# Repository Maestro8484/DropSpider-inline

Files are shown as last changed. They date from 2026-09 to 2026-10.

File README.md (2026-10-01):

# dropspider-inline

**DropSpider, Mechanism A: In-Line Single-Axle Clutch Spool (ISCS), Rev C.1.**
A Halloween prop, mounted on a porch ceiling or turned over on the porch beam's inside face (doc 06), that drops a foam spider 0.5 to 1.2 m when someone walks toward a doorway, then winds it back up and re-arms on its own. Zero power while waiting.

Code: https://github.com/Maestro8484/DropSpider-inline. Project page: https://theschmidtwithin.com/bench/#dropspider

Sibling project name reserved: `dropspider-tiltspool` (Mechanism B, servo-driven tilt-spool free-fall). Not started. This repo is Mechanism A only.

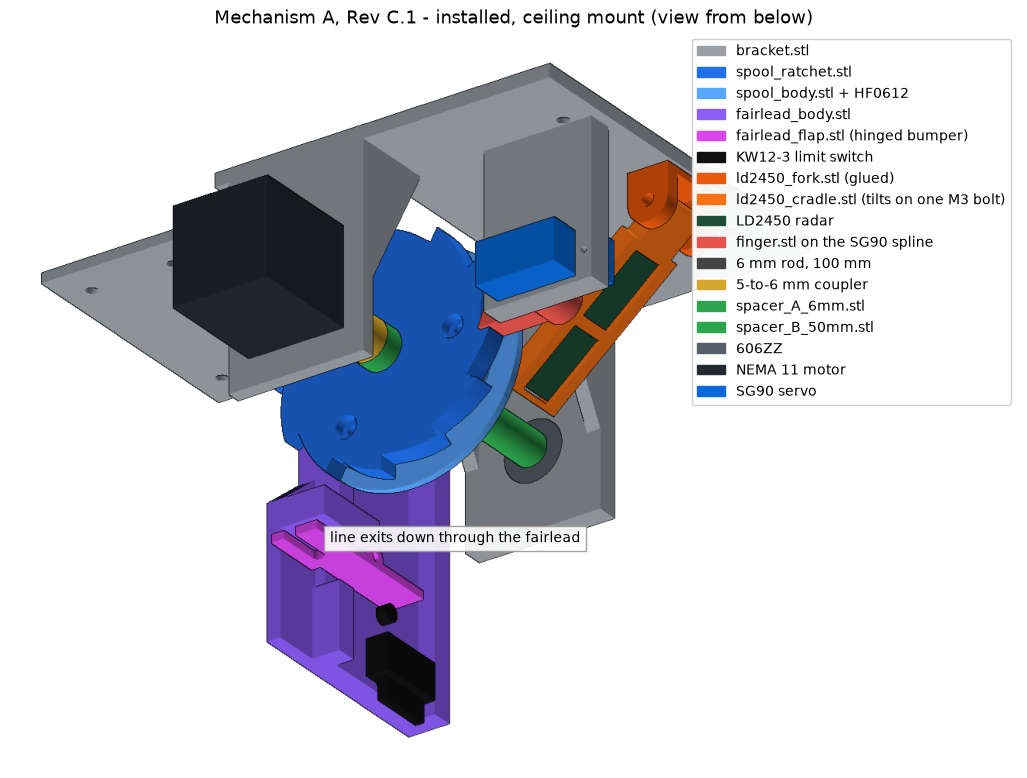
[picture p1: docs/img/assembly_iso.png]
Installed assembly


## How it works

Stepper motor to coupler to 6 mm rod. The spool rides the rod on a one-way clutch bearing. On a drop, the motor spins fast in the unwind direction and the spool runs down behind it; the clutch lets the spool lag but never overrun, so the motor sets the drop speed and the stopping height. On rewind the clutch locks and the motor winds the spider home, where the line's stop bead lifts a hinged flap under the fairlead and clicks a limit switch. A servo-driven finger in a ratchet then holds the spool with no power. An LD2450 radar at the door fires only on people walking toward it, timed so the spider arrives as they reach the doorway.

## Repo map

Each doc has one job, marked in bold below where it matters: a **handoff** holds only work still to do, finished work goes to the **changelog**, the order of future work is the **roadmap**, problems go to the **issues** list, bench results to the **log**, and everything else describes the device as it is now.

| Path | What |
|---|---|
| `docs/01_mechanical_design.md` | design spec, stack-up, lock mechanism, direction rules, print settings |
| `docs/02_electrical.md` | pin map, power, driver setup, logic-level check |
| `docs/03_sensor.md` | LD2450 (primary) and LD2410C (fallback): placement, trigger rule, app check |
| `docs/04_firmware.md` | cycle, serial commands, rewind math |
| `docs/05_assembly.md` | step-by-step assembly with pictures |
| `docs/06_installation.md` | doorway geometry, heights, fastening, safety |
| `docs/07_commissioning.md` | bench and on-site test checklist with pass criteria |
| `docs/08_open_items.md` | **issues:** what is verified, what is not, risks; closed items one line each |
| `docs/09_fairlead_switch.md` | fairlead, hinged flap and KW12-3 limit switch |
| `ROADMAP.md` | **roadmap:** every piece of work still to do, in order, one line each |
| `CHANGELOG.md` | **changelog:** finished work, newest first |
| `docs/handoff_task1_firmware.md` | **handoff:** bench tests T1 to T8, and the spool-to-flap fix before them |
| `docs/handoff_spool_onepiece.md` | **handoff:** one-piece spool and ratchet, no supports, bearing hole that grips, separator clear of the finger |
| `docs/handoff_sensor_bearings.md` | **handoff:** the LD2450 radar as the trigger (the name is historical; bearing care is in doc 01) |
| `docs/M1_fix_handoff.md` | **reference:** the Rev C.1 clutch fix and motor-led drop, why it works, and the T1 to T8 test table (the name is historical) |
| `cad/generate.py`, `cad/fairlead.py`, `cad/inverted.py` | source of truth for every printed part (`inverted.py`: the device turned over on the porch beam, doc 06) (`tools\regen_cad.ps1` rebuilds STLs and images) |
| `cad/stl/` | print-ready files. `cad/retired/` holds obsolete parts and their code, `docs/retired/` obsolete docs and pictures: do not print or follow them |
| `platformio.ini`, `src/`, `include/` | firmware, standard PlatformIO layout, 30-pin ESP32 DevKit V1 (38-pin NodeMCU-32S also works) |
| `secrets.ini.example` | template for `secrets.ini`: WiFi name, password, update password (never committed) |
| `docs/commissioning_log.md` | **log:** every bench and install result, dated, failures included |
| `bom/BOM.csv` | every part, ordered or still to buy |
| `scripts/update_firmware.bat` | double-click to update the firmware, by WiFi or by USB |
| `tools/esptool_noreset.py` | USB flashing helper the update script uses |
| `tools/console.py` | send console commands over USB or the network, print the replies |
| `tools/requirements.txt` | Python packages for the tools |
| `tools/*.ps1` | same as the .bat files for PowerShell; regenerate CAD and images |

## Quick start

1. Print the parts in `cad/stl/` (settings in doc 01).
2. Buy the "TO BUY" lines in `bom/BOM.csv`.
3. Assemble per doc 05.
4. Wire per doc 02. Meter the 5 V buck (must read 4.95 to 5.05 V) and set driver Vref to 0.85 V first.
5. Copy `secrets.ini.example` to `secrets.ini` and put in your WiFi name and password.
6. Plug the board in by USB, double-click `scripts\update_firmware.bat`, pick 2 (USB), then run doc 07 on the bench.
7. From then on, the web page at `http://dropspider.local` is the console, and firmware updates go over the network (doc 04).
8. Install per doc 06.

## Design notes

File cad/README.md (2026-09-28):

# cad/ - how the parts and pictures are made

Read this before changing any printed part or any picture in `docs/img`. It is the working memory for CAD in this repo.

## The short version

There is no CAD program. Every printed part is Python code. Run the code and it writes the STL files, checks them, and draws the pictures.

```powershell
pip install trimesh manifold3d shapely numpy matplotlib      # once
.\tools\regen_cad.ps1                                          # rebuild everything
```

`tools\regen_cad.ps1` runs three scripts in order:

| Step | Script | Writes | What it does |
|---|---|---|---|
| 1 | `cad/generate.py` | `cad/stl/*.stl` | Builds each part from boxes and cylinders, adds and cuts them (boolean operations, via manifold3d), turns each part to its print orientation, exports STL, then runs checks and prints a report |
| 2 | `cad/render.py` | `docs/img/` assembly, exploded, step1 to step6, lock_detail, base_layout, fairlead_rest, fairlead_home, fairlead_exploded, inverted_install | Places every part where it sits in the real device and draws shaded pictures with `raster.py` (a small built-in renderer, no graphics card needed). Takes 1 to 3 minutes |
| 3 | `docs/diagrams.py` | `docs/img/wiring.png`, `install.png` | Flat drawings made with matplotlib |

Same code, same output: the pictures and STLs are rebuilt identically every time.

## Files

| File | Holds |
|---|---|
| `generate.py` | Every part except the fairlead unit: bracket, spool body, ratchet disk, finger, spacers, shims. The `PARTS` table maps file names to functions. `assembly()` places every part in its installed position |
| `fairlead.py` | Fairlead body, hinged flap, KW12-3 switch model, hinge math. Run it on its own for the flap travel report |
| `sensor_mount.py` | LD2450 radar mount: the fork's ears and the cradle and `ld2450_fork_screw`, the bolted fork (2x M3, no glue), the only radar fork, cradle tilting on one M3 bolt. Run it on its own for its fit report: clear of every part at every tilt from 0 to 50 degrees |
| `inverted.py` | Inverted install (doc 06 alternative, approved 2026-09-27): the device turned over on two steel corner braces. `bracket_inverted()` (the 3 drilled holes), `fairlead_base()` (doc 09's unit as a block under the base, exported as `fairlead_base.stl`), the radar turned over under the servo end, brace stand-ins, a board box, `assembly_inverted()`, `porch()` and `view_inv()` (pictures with the floor down). Run it on its own for its report: watertight, face flat, clash (braces and board box included), radar view, line path, spool clearance, flap stops and roller push, screw heads, loads, heights |
| `retired/` | Obsolete parts and their code: `line_guide`, the glued `ld2450_fork`, the wall-install drafts (`wall_hinge.py` with hinge_plate, hinge_clip, tie_bar, strut; `wall_mount.py`, the braced shelf). Kept for reference, not run, not printed |
| `render.py` | All 3D pictures. One function per picture |
| `footprint_svg.py` | Laser-cutter SVG of the bracket's ceiling face with every hole, 1:1 mm, seen from below: writes `bracket_footprint.svg` in cad/, and `bracket_footprint_inverted.svg` with the three holes drilled for the inverted install |
| `raster.py` | The renderer (hidden surfaces, shading, outlines) |
| `stl/` | Print-ready output. Never edit these by hand |

## The coordinate frame (every doc uses it)

Units: millimeters.
- **y = 0** is the ceiling face of the bracket. **+y** points down toward the floor.
- **z = 0** is the outer face of the motor plate. **+z** runs along the rod toward the 606ZZ bearing plate.
- **Rod axis** at x = 0, y = 40. Servo tower on **+x**. Electronics pad on **-x**.
- **Line** leaves the spool at x = -25, z = 45 and runs straight down (+y) through the fairlead.
- Every clockwise or counterclockwise is seen from behind the motor (owner 2026-09-28): looking from -z along the rod toward the 606ZZ end. Spider falling = counterclockwise, winding up = clockwise, the HF0612 locks when the rod turns clockwise.
- Inverted install (`inverted.py`): the same frame, so y = 0 is the base's outer face and +y points UP in the porch. The line leaves the spool at x = 25, z = 45 and runs through the base (-y). Its pictures use `view_inv()` so the floor is down.

## Checks the scripts run (read the report every time)

| Check | Where | Pass |
|---|---|---|
| Every part is a closed solid (watertight, printable) | generate.py | `watertight=True` on every line |
| Nothing touches the spinning spool, 2 mm clearance | generate.py | `0.0 mm3 overlap` for bracket, fairlead_body, servo |
| No clashes between moving and fixed parts | generate.py | no `CLASH` lines |
| Finger tip reaches into the tooth root | generate.py | `engaged: True` |
| Finger seats in a tooth gap (rotates the ratchet through one tooth pitch in 0.25 degree steps) | generate.py | `True (window 6.75 to 11.75 deg)` for the Rev C.1 finger |
| Flap hard stop and switch travel | `python fairlead.py` | hard stop about 14.75 deg; roller push at least 3.4 mm |
| Line path open through the fairlead bore and the flap slot | `python fairlead.py` | `line path clear ... True` twice (a flipped bore once printed solid) |

## Changing a part: the routine

1. Edit the part's function in `generate.py` or `fairlead.py`. Keep dimensions as named constants at the top where they already are.
2. Run the checks (`python fairlead.py`, `python inverted.py`, `python sensor_mount.py`, as the part needs; they only print) and read the report. Any `CLASH`, `watertight=False`, or lost clearance means stop. Export only the changed part's STL (`G.PARTS["name"]()`), not every STL (owner 2026-09-27: update only the parts that need it).
3. Re-render a picture only if the owner asks for it.
4. Update the doc that describes the part (01 for the spool, finger and bracket, 09 for the fairlead).
5. Tell the owner which STL changed and whether an already-printed part is now out of date.
6. Geometry changes need the owner's approval (CLAUDE.md hard constraints).

## Lessons already learned (do not repeat these)

- **Print orientation lives in code.** Parts that must print a certain way have a `*_print()` function that turns them before export. Never ask the owner to rotate in the slicer.
- **Recesses face up.** A recess on the bed side leaves a ceiling with nothing under it; Bambu Studio reports "floating regions" or "isolated object". The finger v1 failed this way.
- **No overhangs on the spool.** The spool is two parts (body and ratchet disk) so both print flat with zero supports and no scars in the line channel. The spool hub must end flush with its flange; a stub under the flange forced supports once.
- **Thin features fail in PLA.** Keep printed walls at 1.2 mm or more near loads. Finger v1 had 0.9 mm walls and a half-width tip; the current finger is 7 mm wide with a 7 mm plate.
- **Tip shapes must match the teeth.** An unbeveled 7 mm finger could not seat in any tooth gap. The 20 degree bevel on the ramp side fixed it. Re-run the seating check after any finger or tooth change.
- **Nothing may stick out of the ceiling face** (y = 0). That is why the fairlead's two M3 screws are countersunk flush (owner: no glue).
- **Directions are easy to get backwards.** One-way clutch: it only lets the spool overrun in the direction the rod can drive it (flaw M1). Check any direction claim against the frame above before writing it into a doc.
- **The bracket is printed and final.** Changes should bolt or screw to it, not require reprinting it. No glue (owner 2026-09-26).

- **Printed holes come out small on the owner's printer.** A 4.8 mm socket printed 4.5; a 10.0 spacer in a 10.2 hole was too tight. Draw slide fits 0.2 to 0.3 mm a side bigger, and free-turning pins about 0.25 mm a side. A fit check (2026-09-26) found 9 fits wrong; see the git log. **Bearing press fits: the HF0612 would not go into a 10.0 hole, 10.2 was tight, and a 10.7 hole printed at 10.7 and was loose (owner 2026-09-28).** Its hole is now drawn 10.3 (firm press); the disk's stub hole is the same 10.3. The 606ZZ seat drawn 16.8 would not take the bearing even heated (2026-09-27); it is drawn 17.0, not yet fitted.
- **A boolean cut can silently miss.** The fairlead bore once sat at y -78 because of a sign flip, so the part printed solid. Every functional void now has a check that fails if it misses (line path check, flatness check in `fairlead.py`).
- **A face something mounts on must be one plane.** Check the distinct levels of the faces under it (the switch face and the fairlead's mounting face each had a 0.8 to 1 mm step the owner had to shim).
- **A recess on the bed side needs stepped bridging**, or it prints a roof over air. The finger's screw-head recess uses it: two strips, then a square, then the round hole.
- **Every member starts on the bed plane**, and ribs run the full height to both ends.
- **`lbl()` in render.py takes render-world coordinates, (x, z, -y), not assembly coordinates.** A label given (x, y, z) lands somewhere else on the page (wall_install.png, 2026-09-27).
- **An L-bracket with two end braces cannot print on its side** (the prior-art advice for a strong corner): the second brace would hang over air. It prints shelf-down with the plate and braces standing; the braces keep the corner's layer bonds under 1 MPa, so the weaker orientation costs nothing that matters.

## Adding a new picture

Write a function in `render.py` that builds a list of `(mesh, color)` pairs from `G.assembly()` (or from parts moved apart for an exploded view), calls `raster.render(items, elev=..., azim=..., W=..., H=...)`, and saves with `save()`. Add the function to the `__main__` line at the bottom so `regen_cad.ps1` builds it. Use `rview()` so the ceiling is at the top of the picture.

## Known limits

- Python 3.10 or later. `trimesh` path functions that need `rtree` (area of a cross-section) are avoided; install `rtree` if you add one.
- Rendering is CPU only; big pictures take a minute or two.
- The owner's chat session can edit these text files but cannot write STL or PNG files into the repo. After an owner CAD change, run `regen_cad.ps1` here.

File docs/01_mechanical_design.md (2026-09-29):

# 01 - Mechanical design: Mechanism A, In-Line Single-Axle Clutch Spool (ISCS), Rev C.1

Status: **released for build, Rev C.1** (clutch flipped, motor-led drop; see `M1_fix_handoff.md`). Owner: lead mechanical engineer. Source of truth for geometry: `cad/generate.py`.

Installed assembly

## What it does, in one paragraph

A foam spider hangs on 6 lb nylon monofilament fishing line wound on a spool. The spool sits on a one-way clutch bearing (HF0612) on a steel rod driven by a small stepper motor. A servo-held finger locks the spool at the top with zero power. On trigger, the motor winds a hair to lift the tooth off the finger, the finger swings out, and the motor spins fast in the unwind direction. The spool runs down behind it on the clutch: it can fall as fast as gravity allows but never faster than the motor, so the motor sets the top speed and the stopping point. After a short hang, the motor winds the spool back up (the clutch locks in that direction), the finger swings back into the ratchet teeth, the motor eases the spool down onto a tooth, and everything powers down.

## Why this layout (decisions already made, do not re-open without cause)

| Decision | Reason |
|---|---|
| Spool on a one-way clutch, motor-led drop (Rev C.1) | A one-way clutch only lets the spool overrun in the direction the motor drives, so the spool cannot free-fall past a stopped motor (flaw M1 in Rev C). Instead the motor runs ahead in the unwind direction; the spool lags behind it at gravity and can never overrun it. The unpowered motor's drag (measured too high) never matters because the motor is always driven. |
| Everything on one rod ("in-line") | Strength and simplicity: no gears, belts, or offset shafts. One part to align. |
| Ratchet + servo finger for the hold | Zero power while armed, no hum, no heat. The load pushes the finger onto a printed ledge, not into the servo. |
| Stepper, not a DC gearmotor | Fixed step count per move; the fairlead's limit switch marks home. |
| Hard stop at the top = bead lifts a hinged flap under the fairlead, which presses a KW12-3 switch; the flap then bottoms on the fairlead (Rev C.1, doc 09) | Rewind length varies by up to half a turn after each drop (see "End of drop"), so a counted stop alone is not reliable. |
| Spool split into two parts | Both print flat with zero supports; no support scars in the line channel. |

## Parts on the rod, motor to bearing (z = distance from the motor plate's outer face)

| z (mm) | Part | Notes |
|---|---|---|
| -32 to 0 | NEMA 11 motor | Mounted on the outside of the motor plate, 4x M2.5 |
| 10 to 30 | 5-to-6 mm rigid coupler | Motor shaft fills the 5 mm side. Blue Loctite on both set screws. |
| 20 to 120 | 6 mm hardened rod, 100 mm | Clamped in the coupler only; everything else slides on it |
| 30 to 36 | spacer_A_6mm | 12 mm across, so it stops on the ratchet disk's face instead of dropping into its 10.3 mm center hole. Sets the disk in the finger plane. Adjust with shims (see below). |
| 36 to 43 | spool_ratchet | 12 teeth, full 7 mm (tip r 33, root r 29); a plain plate, flat both faces. The finger engages z 36 to 42, so the shield on the z 43 face clears the finger by 1 mm |
| 43 to 44.5 | spool_shield | Flat 1.5 mm disc, 64 mm across like the spool flange: keeps the line off the teeth. Clears the finger's top (z 42) by 1 mm |
| 44.5 to 50 | spool_body with HF0612 pressed in | Flat face on the shield; line channel z 44.5 to 48. The HF0612 (z 38 to 50) runs through all three parts and centres them; 3x M3x8 from the motor side, heads 5 deep in the disk |
| 50 to 100 | spacer_B_50mm | 9.6 mm across; the last 1 mm at the 606ZZ end is 8 mm across so it presses only on the bearing's inner ring, not its shield |
| 100 to 106 | 606ZZ in the bearing plate | Supports the rod end |

**The one measurement that matters:** the ratchet disk must straddle the finger. Finger plate is z 35 to 42 (7 mm thick); disk is z 36 to 42. After the motor and coupler are on, measure from the motor plate's outer face to the coupler's free end. If it is not 30 mm, change spacer A by the difference using `shim_1mm` / `shim_2mm` (or reprint spacer A). The spool floats between spacer A and spacer B, so the stack must be snug, not tight.

## The lock (read this before touching the servo angles)

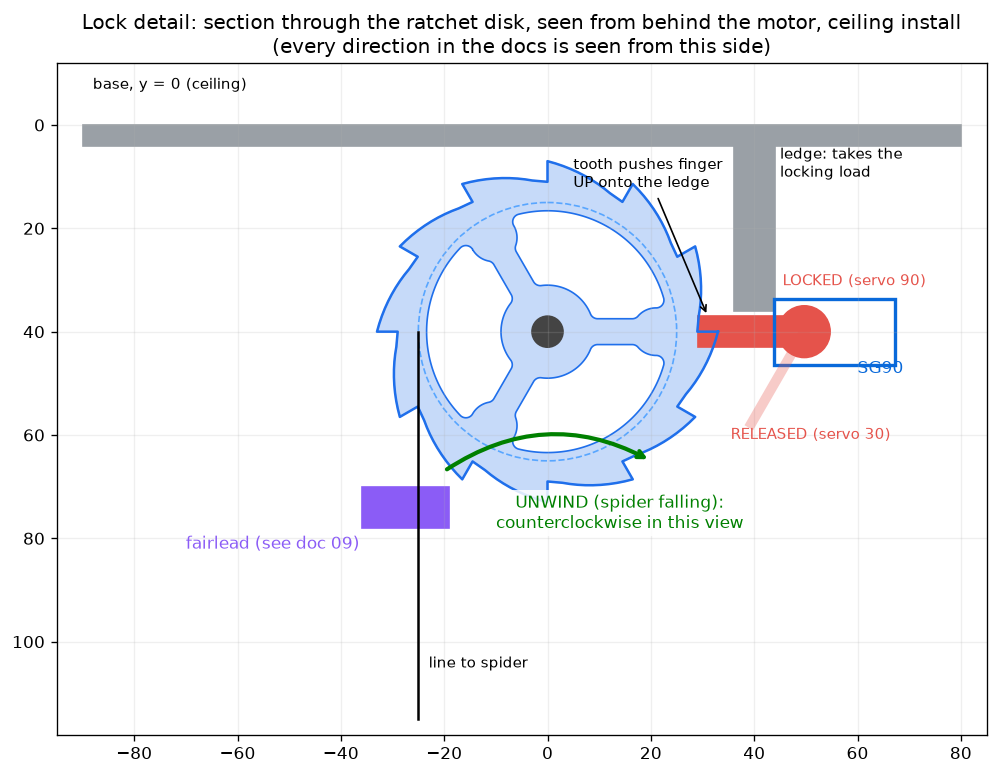
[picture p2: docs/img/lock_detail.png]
Lock detail


- **Every direction in these docs is seen from behind the motor**: standing behind the stepper motor, looking along the rod toward the spool (the picture is drawn that way). The spool turns **counterclockwise** when the spider falls and **clockwise** when it winds up.
- The steep faces of the teeth block that direction. The tooth pushes the finger toward the ceiling, onto the **ledge** printed on the bracket. The ledge takes the load; the servo carries almost none.
- Finger locked = level, pointing at the rod (default servo 90). Released = swung toward the floor by 60 degrees (default servo 30). Both are set at commissioning.
- Lock sequence (firmware does this): motor holds the spool, finger goes in, motor eases the spool down (counterclockwise) up to 1/12 turn until a tooth lands on the finger, the clutch then slips so the motor runs on alone, motor off, servo lets go.
- Release sequence (M2): with the spider hanging, the tooth pins the finger. The motor winds the spool clockwise about 1/12 turn while the finger swings out, so the finger rides up the tooth's ramp. Never release with the motor off.
- The finger (Rev C.1) is 7 mm wide and 7 mm thick, level with the ledge it rests on (z 35 to 42); the ratchet disk is z 36 to 42, so a spline 1 mm higher or lower than expected still leaves 5 mm of finger on the disk. Its tip face is beveled 20 degrees so the corner on the ramp side sits 2.5 mm back; the steep-face side reaches full depth. Checked in CAD: it seats in a tooth gap over a 5 degree window. No horn: a hub under the finger reaches down onto the SG90 spline (4.8 mm across the teeth, 3.4 mm tall, tip about 2 mm short of the ledge, all measured by the owner). The socket is drawn 5.0 mm so it prints about 4.7 (a 4.8 drawing printed 4.5 on the owner's printer), a light press on the spline. The spline tip bottoms on a 1.5 mm floor, which sets the height; the horn screw goes in from the top through a 7.4 mm recess (prints about 7.1). Print it flat top face down (as exported); the hub stands up.

## Direction rules (the only things that can be assembled backwards)

1. **Line exits on the electronics-pad side** of the spool and goes straight down through the fairlead. Wind it so pulling the line spins the spool counterclockwise, seen from behind the motor. **Inverted install (doc 06):** the line exits on the **servo side** (x 25) and goes through the 5 mm hole in the base; the winding sense, the clutch, the finger and the firmware `dir` are all unchanged, because the spool still turns counterclockwise (seen from behind the motor) when the spider falls. The finger's own weight now rests it toward the ledge.
2. **HF0612 orientation (Rev C.1, flipped from Rev C):** with the spool on the rod and the rod held still, the spool must **lock counterclockwise** (seen from behind the motor) and spin freely clockwise. Put the other way: the rod turning clockwise drives the spool. If backwards, press the bearing out and flip it.
3. **Motor rewind direction:** set in firmware (`dir 0/1`), no rewiring.

## Line and hard stop

From the spool outward: **6 lb nylon monofilament** (clear fishing line, tied straight to the barrel with an arbor knot; no elastic, no braid, owner's call 2026-09-26), through the fairlead (3.2 mm throat) and the flap's slot, then the **8 mm hard plastic bead** (lifts the flap at home; too big to pass the slot), then a small barrel swivel (stops the spider spinning the line into twists), then the spider.

Why monofilament: it winds cleanly, it is nearly invisible, it is gentler on the PLA fairlead than braid, and it stretches (roughly 15 to 25 percent before it breaks, a typical figure for nylon mono, not measured here). That stretch is the shock absorber. At 6 lb (about 27 N) it is also a fuse: it snaps before it can pull the device off the ceiling.

## End of drop and why the line must stretch

Rev C.1 note: the motor now stops the spider short of the knot on every normal drop, so this slam only happens if the motor loses its grip mid-drop. The line's own stretch is the backstop.

The spool is free, so nothing stops the spider until the line runs out. At that moment the knot swings to the bottom of the barrel and the pull goes straight into the rod. Without give in the line (braid), a 100 g spider falling 0.7 m produces a shock of order 100 N or more, enough to snap the knot, the PLA, or the ceiling anchors. About 750 mm of 6 lb mono stretches roughly 70 mm and holds the peak near 12 N for a 60 g spider (estimate from the typical stretch above), under half its breaking strength, and the spider bounces. **Never swap in braid or fluorocarbon (both stretch little) without putting a 150 mm elastic snubber back at the barrel.**

The same swing means the knot can end up to half a turn either side of the bottom, which is why the rewind overshoots by 0.75 turn and relies on the bead stop.

## Materials and print settings

| File | Qty | Orientation | Infill | Walls | Supports | Brim |
|---|---|---|---|---|---|---|
| spool_body.stl | 1 | as exported, flange down | gyroid 40% | 4 | none | none |
| spool_ratchet.stl | 1 | as exported: flat shield face down, counterbores up | gyroid 40% | 4 | none | none |
| spool_shield.stl | 1 | as exported, flat | gyroid 40% | 4 | none | none |
| bracket.stl | 1 | base down | gyroid 40% | 4 | tree, **not** build-plate-only | none |
| fairlead_body.stl | 1 | as exported (flat side down) | gyroid 40% | 4 | none | 5 mm (big flat footprint, stops corner lift) |
| fairlead_flap.stl | 1 (+1 spare) | as exported (flat side down) | rectilinear 100% | 4 | none | 5 mm, 0.1 gap |
| ld2450_cradle.stl | 1 | as exported (flat, face plate down, 6.7 mm tall) | gyroid 40% | 4 | none | none |
| finger.stl | 1 (+1 spare) | as exported (flat top face down, hub standing up) | rectilinear 100% | 4 | none | 5 mm, 0.1 gap |
| spacer_A_6mm.stl, spacer_B_50mm.stl | 1 each | on end | rectilinear 100% | 4 | none | 5 mm, 0.1 gap |
| shim_1mm.stl, shim_2mm.stl | only if needed (05 step 8) | flat | rectilinear 100% | 4 | none | none |
| fairlead_base.stl | 1, inverted install only (doc 06), instead of fairlead_body | as exported (17 mm tall) | gyroid 40% | 4 | none | 5 mm |
| ld2450_fork_screw.stl | 1, both installs: the only radar fork, bolted with 2x M3, no glue (the glued ld2450_fork is retired) | as exported (plate face down, ears standing up) | gyroid 40% | 4 | none | none |

PLA for everything. Print the finger in PETG if any is loaded. 5 top and bottom layers. `cad/retired/line_guide.stl` is obsolete; do not print it.

## Press fits and fasteners

- HF0612 into spool body: the hole is drawn 10.3 mm for the 10.0 mm bearing, a firm press (owner 2026-09-28: 10.0 would not take the bearing at all, 10.2 was tight, and 10.7 printed at 10.7 and was loose). The disk's center hole over the stub is the same 10.3 mm. Press in with a vise or clamp. Too tight: warm the hub with a hair dryer. Too loose: one drop of CA on the outside. Never glue near the rollers.
- 606ZZ into bracket: drawn 17.0 mm for the 17.0 mm bearing; it prints 0.1 to 0.2 small, which is the press. Same method. (Was 16.8: would not go in even heated, owner 2026-09-27.)
- Spool disk to body: 3x M3x8 self-tapping into 2.5 mm holes.
- Fairlead body to pad: 2x **M3 countersunk (flat-head) screws, 8 to 10 mm**, put in from the ceiling side down through the x = -32 pad holes, heads flush with the ceiling face, cutting their own thread into the fairlead's rail (2.5 mm pilots). No glue (owner 2026-09-26). The pad holes need a 90 degree countersink so the heads sit flush: new bracket prints have it; on an already printed bracket, twist an 8 mm drill bit by hand in each of the two holes from the ceiling side until a screw head sits flush or just below. Nothing may stand proud of the ceiling face, which is why the heads are countersunk. At home the motor's pull lands on the fairlead's flap stop, about 2 N.
- KW12-3: 2x M2 x 12 + nuts through the slotted holes. Hinge pin: an M2 bolt, 16 to 20 mm, threaded into the body, free in the flap (filament was too tight, owner 2026-09-26).
- Motor: 4x M2.5x6.
- Inverted install (doc 06 alternative): 2x M3 x 12 (fairlead_base, from inside the base, cutting their own thread), 2x M3 x 10 + nuts (radar fork, nuts inside). Brace screws and bolts are the owner's. The wall install draft's fasteners are superseded.
- SG90: its own two tab screws.

## Bearing care

- **HF0612:** never clean with carb cleaner or solvent spray; it strips the grease and attacks the plastic roller cage. If gritty: isopropyl alcohol flush, dry, one drop of light machine oil. Never grease it.
- **606ZZ:** shielded and greased for life; leave it alone.
- Sluggish drop: check spool end play (0.3 to 0.5 mm), then the fairlead bore, then the HF0612 by hand. See `handoff_sensor_bearings.md`.

## Limits of this revision

- Ceiling mount only. Wall mount changes where the line exits and the fairlead does not fit.
- Spider: soft foam, **60 g or less** (Rev C.1: the motor must stop it at the end of the drop), nothing hard or pointed.
- Drop length set by line length, about 0.5 to 1.2 m.

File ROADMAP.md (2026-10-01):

# Roadmap

Every piece of work still to do, in order. One line each; the handoff holds the detail. Finished work goes to `CHANGELOG.md`, problems and unknowns to `docs/08_open_items.md`, bench results to `docs/commissioning_log.md`. Rules for these files: the `repo-docs` standard in the owner's global Claude setup.

| # | Work | Whose | Status | Detail |
|---|---|---|---|---|
| 1 | Firmware: line between the spool and the flap is about 72 mm in the inverted install (fairlead v2) (firmware assumes 40); factory drop distance must fit the shorter line | team | next | `docs/handoff_task1_firmware.md` step 1 |
| 2 | Bench tests T1 to T8 of the Rev C.1 motor-led drop, with the mechanism assembled | team with the owner | next, needs the mechanism built | `docs/handoff_task1_firmware.md` |
| 3 | One-piece spool and ratchet: no supports, bearing hole that grips (the HF0612 slips a bit), separator inside the finger's reach (the finger caught the shield and was cut back) | team with the owner | later: the owner keeps the current stack (2026-10-01) | `docs/handoff_spool_onepiece.md` |
| 3b | Build the inverted install: print `fairlead_base` and `fairlead_flap_inv` (fairlead v2), `ld2450_fork_screw`; drill the five base holes; braces and their holes | owner | any time; bench first | build guide sections 06 and 11, doc 06, open item V18 |
| 4 | LD2450 radar as the trigger, including the spider-in-view problem; tests S1 to S5 | team | waiting on T1 to T8 | `docs/handoff_sensor_bearings.md` |
| 5 | Hang it on the porch, walk tests, arm | owner with the team | waiting on 2, 3 and 4 | `docs/07_commissioning.md`, build guide section 12 |
| 6 | Calibrate card on the web page: walks the bench steps with Pass and Fail buttons (replaces the planned `test` console command) | team | later | build guide section 09, "Planned" |
| 7 | Enclosure for the controller board | owner | later | `docs/08_open_items.md`, Rev D candidates |
| 8 | Static IP address (DHCP only today) | team | later, only if the router moves it | `docs/08_open_items.md`, known limits |

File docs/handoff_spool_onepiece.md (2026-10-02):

# Handoff: one-piece spool and ratchet (Rev C.3)

**Later, not now:** the owner keeps the current three-part stack and its cut-to-length shims (2026-10-01); this is the plan for the next spool. Redesign the three-part spool stack (`spool_ratchet`, `spool_shield`, `spool_body`) as one part that prints with no supports, grips the HF0612 one-way bearing so it cannot turn in its hole, and keeps the line separator out of the finger's reach. For a CAD session working with the owner (Joe).

## Ground truth first

This file is a work order, not a record. The repo on disk wins: `cad/generate.py` is the source of truth for every dimension below. If this file and the code disagree, the code is right and this file is stale; say so out loud. Staleness check:

```
git log -1 --oneline                                   # where the repo is now
git log -1 --oneline -- docs/handoff_spool_onepiece.md # when this file was last true
```

## Before you start

1. **The bearing turns in the plastic** (owner confirmed 2026-10-01), only under more load than the spider's weight; the clutch on the rod is fine. Step 3 fixes it.
2. **What is left of the finger.** Joe cut about 5 mm off the finger's face with flush cutters so it stopped catching the separator disc. Ask whether he cut its thickness (along the rod) or its length (toward the teeth), and how much finger now sits on the ratchet teeth (look edge-on at the lock angle). Either cut means less tooth engagement than the design's 7 mm; the new spool must let a fresh, uncut `finger.stl` work.
3. **Bearing hole 0.1 mm smaller.** Joe confirmed 2026-10-01: 10.3 to 10.2 (10.2 printed tight before; 10.3 now slips a bit under more load than the spider's weight).
4. Run `cd cad; python generate.py` and confirm every check passes before changing anything, so a later failure is yours.

## Read first

1. `CLAUDE.md`, especially the direction rule (every clockwise is seen from behind the motor) and "edit `cad/generate.py`, never the STLs".
2. `cad/README.md`: frame, rebuild routine, checks, lessons (the HF0612 press-fit history is there: 10.0 would not take it, 10.2 tight, 10.7 loose, 10.3 chosen).
3. `cad/generate.py`: `spool_ratchet`, `spool_shield`, `spool_body`, `ratchet_poly`, `spoke_windows`, `hole_chamfer`, `finger`, the finger seating check, and `assembly()`.
4. `docs/01_mechanical_design.md`, the stack table (z 30 to 106) and the print table.
5. `docs/05_assembly.md` steps 1 to 9 and the build guide's spool steps, which this part changes.

## The work, in order

1. **One part, three zones along the rod.** Ratchet (12 teeth, tip r 33, root r 29, ramps rise clockwise and steep faces block counterclockwise, seen from behind the motor; keep `ratchet_poly`), then a separator, then the barrel and the far flange. No screws, no counterbores. The HF0612 presses in from the flange side as now.
2. **Separator smaller than the finger's reach.** Today's shield is r 32, out past the finger's tip (closest approach r 29.38), so when Joe shimmed the stack along the rod the finger rode onto it. Make the separator r 28 or less (at least 1 mm inside the finger tip), so the finger can overlap it along the rod and never touch it. It only has to keep the line off the teeth: about 720 mm of 6 lb mono is under 5 turns on the r 25 barrel, one layer. Check that claim against the line length in doc 06 and say the margin in the report.
3. **Bearing hole that grips.** Standard printed press-fit: crush ribs (small ribs that the bearing shaves flat as it goes in) rather than a plain round hole. Owner's number is a plain 10.2 hole; offer crush ribs (10.4 hole, 6 to 8 ribs reaching in to 10.1) as the alternative if 10.2 needs sanding to go in, plus the existing 0.4 lead-in chamfer at the flange side. Name the source you borrow the rib sizes from (guard 2: prior art first).
4. **Prints with no supports, lying on one face.** Recommended: ratchet face on the bed (the teeth are plain vertical walls; the separator and barrel are smaller, so they stand on it with no overhang). The far flange then overhangs the barrel: give its underside a 45 degree chamfer, or keep it no wider than a 45 degree slope allows. The barrel is only about 3.5 mm wide today; there is room to widen it along the rod (Joe's build needed about 4 mm of shim on the motor side and 5 mm on the 606ZZ side, and spacer B is 50 mm), so take width from the shims rather than steepening the chamfer. Every hole edge on the bed gets the 0.4 chamfer.
5. **Line anchor built in.** Today the owner drills it by hand (`docs/05_assembly.md` step 5); the new part should have it printed in. What it must do: hold the 6 lb mono so it can never slip round the barrel, even when the spider runs all the line out (about 27 N, the line's breaking pull), with no glue doing the holding and nothing touching the rod.
   - **Where:** one hole through the barrel skin, in the middle of the barrel's width (between the separator and the far flange), at a spot where a spoke window lies behind the skin, midway between two spokes so a spoke never blocks it.
   - **How the line goes:** in through the hole from outside, out through the window's open end at the far flange face, tied round a 10 mm stub of 1.75 mm filament (a double overhand knot), pulled back so the stub lies across the hole inside the window. A drop of CA on the knot only. The stub cannot pull through.
   - **Hole shape:** about 1.2 mm drawn (printed holes under about 1 mm close up; check it takes a 1 mm drill). With the part printed ratchet down, the hole runs sideways, so draw it as a teardrop with the point up so its roof prints without sagging. Angle it so the line leaves the barrel along the winding direction (clockwise, seen from behind the motor), so the first turn wraps over the line's tail and the line never kinks at the hole's edge. Round the outer edge of the hole (0.4) so it cannot nick the line.
   - **Window side:** leave the window big enough for fingers or tweezers to fish the line out and seat the stub, and check the stub (10 x 1.75 mm) lies inside the window clear of the hub and the HF0612 at every angle.
   - **Alternative to offer, not the default:** a printed post or bar across the window to tie round instead of the filament stub. It saves the stub but is harder to tie in a small window; the stub is what the owner uses now.
   - **Ruled out:** an M3 set screw in the spool as the anchor (owner asked 2026-10-01). A screw into the rod locks the spool to the rod and defeats the one-way bearing; a screw onto the HF0612's thin drawn-steel shell bends it and jams the rollers.
6. **Keep the light-weight windows** (`spoke_windows`) if they still print with no bridging in this orientation; they run straight through along the rod, so they should.
7. **Fit the stack along the rod.** Total length, spacer A and spacer B (or new shims) must put the ratchet teeth across the finger's full 7 mm with the separator clear. Write the new z table.
8. Export only the new part's STL, `spool_onepiece.stl`. Move `spool_ratchet`, `spool_shield` and `spool_body` to `cad/retired/` with a one-line "Retired, superseded by spool_onepiece" note, once Joe has the new one in hand.

## Tests

Run in the model, results in the session report and the changelog line:

- `python generate.py`: finger seating check passes (seats in a tooth gap), no clashes, swept clearance clear, with a fresh uncut finger.
- Finger to separator: no contact with the stack slid 5 mm either way along the rod (Joe's shim range).
- Overhang report for the print orientation: nothing off the bed steeper than 45 degrees except the windows' straight walls.
- `python inverted.py`: line path and every inverted check unchanged.

On the bench, logged by Joe in `docs/commissioning_log.md`: the HF0612 presses in by vise and does not turn in the hole under a hand twist against the lock; spool free clockwise and locked counterclockwise with the rod held (seen from behind the motor); finger drops into the teeth at the lock angle with no catching.

## Done when

`spool_onepiece.stl` is printed, the bearing holds, the finger engages a fresh uncut finger with no catching, and the docs say so.

## Rules for the session

- Make the part and stop. Slicer settings are Joe's; answer slicer questions only when he asks.
- Export only the changed STL; no full rebuild, no mass picture regeneration unless Joe asks. Update only the build guide steps and pictures this part touches.
- Every direction is seen from behind the motor.
- Decisions go to Joe as one flat numbered list, the question in bold on each item.
- Plain English, no em dashes, no arrows.

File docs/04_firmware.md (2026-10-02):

# 04 - Firmware

What the code does, how to load it, and every command it takes.

## Where it lives

Standard PlatformIO layout at the repo root. Board in use: 30-pin ESP32 DevKit V1 (PlatformIO board `nodemcu-32s`, same chip as the 38-pin NodeMCU-32S), Arduino framework, platform pinned to `espressif32@6.7.0` (Arduino core 2.0.16).

| File | What |
|---|---|
| `platformio.ini` | board, pinned versions, USB port, network update target |
| `secrets.ini` | network name, network password, update password. Not in git. Copy `secrets.ini.example` |
| `include/config.h` | every pin and fixed number, and the factory defaults |
| `src/main.cpp` | start-up order only |
| `src/machine.cpp` | the cycle, stepper, finger servo, radar pin, BOOT button, limit switch |
| `src/console.cpp` | the text commands, shared by the USB console and the web page |
| `src/web.cpp` | WiFi, the web page, network firmware updates |
| `src/settings.cpp` | tunables saved in flash |

Libraries, both pinned in `platformio.ini`, both downloaded by PlatformIO on the first build:

| Library | Why this one |
|---|---|
| ESP32Servo 3.0.6 | servo pulses from the ESP32's own PWM hardware |
| FastAccelStepper 0.33.14 | step pulses from the ESP32's pulse hardware with speed ramps, so a rewind does not freeze the console or the web page. The Rev C handoff timed each pulse by hand and froze everything for 2 to 3 s |

WiFi, web server, mDNS (the `dropspider.local` name), ArduinoOTA (network upload) and Update (upload page) are all built into the ESP32 core. No other libraries.

## Load the firmware

First time on a new PC: install VS Code and its PlatformIO extension, copy `secrets.ini.example` to `secrets.ini` and fill it in, then open this folder in VS Code.

| Way | How |
|---|---|
| Network | board must be on the network already. Double-click `scripts\update_firmware.bat` and pick 1, or VS Code env `ota` and Upload. No buttons. It retries up to 3 times, because the first try sometimes drops |
| USB | double-click `scripts\update_firmware.bat` and pick 2. It builds and loads it; the 30-pin board goes into flash mode by itself. If a board does not (the first 38-pin board did not), the script asks you to hold BOOT (marked IO0 on some boards), tap EN, let go of BOOT, and writes through `tools/esptool_noreset.py`. Port is COM13 in the script and `platformio.ini` |
| Web page | open `http://dropspider.local/update`, log in as `admin` with the update password, pick `.pio/build/nodemcu-32s/firmware.bin` |

The 30-pin DevKit V1 in use enters flash mode on its own, so VS Code's plain Upload works too. The first 38-pin board did not.

Every network update switches the motor and servo off first. After any update the board restarts and, as always, does not rewind on its own.

## Network

- Joins the home network in `secrets.ini` by DHCP (the router hands out the address). Static address: not yet.
- A different network saved from the web page's Network card wins over `secrets.ini`. Save it empty to go back.
- If it cannot join in 15 s it makes its own network `DropSpider-setup` (password `dropspider`), page at `192.168.4.1`.
- Page at `http://dropspider.local` or at the address printed on the USB console at start-up (`wifi` command prints it again).

## The web page

The web page is the console on your phone or PC. Every button sends a console command, and the page's Console card shows everything the board prints, so the page and the USB console always agree.

| Card | What is on it |
|---|---|
| Status | state, chips (armed, spider home, radar, motor powered, fault), drop count, last trigger, last rewind, last drop as measured by the rewind |
| Run | Drop it now, Arm or Disarm, Stop, Motor and servo off, Clear fault |
| Bench: finger servo | live angle, nudge 1 or 5 degrees, go to lock or release angle, store the current angle as lock or release |
| Bench: motor | jog one turn or 1/8 turn each way, Rewind, Lock, Release |
| Settings | every tunable, applied as you change it; Save settings keeps them after power loss |
| Console | the live log and a command box |
| Network | save a different home network and restart |
| Firmware | link to the update page |

## Cycle (Rev C.1, motor-led drop)

```
READY (armed) --radar or BOOT button-->
  RELEASE: driver on; finger swings out while the motor winds the spool up 1/12 turn (M2),
           wait relms (250 ms)
  DROP:    motor unwinds dropmm at up to droprpm, starting at dropacc and stopping at dropdec;
           the spool falls behind it on the clutch and can never pass it. Motor holds at the bottom
  --settle 1.5 s--> REWIND (stops the moment the limit switch closes; without the switch,
                    the drop + 0.75 turn overshoot and the bead stops on the eyelet)
  --> LOCK (finger in; seat move lets the spool down 1.2/12 turn at 30 rpm onto a tooth,
            the clutch slips once it lands; driver off; servo off 0.7 s later)
  --> LOCKOUT 20 s --> WAIT FOR THE DOORWAY TO CLEAR (radar LOW for 2 s) --> READY
```

- The driver is on from the release to the end of the lock. Never drop with the driver off: the unpowered motor drags too much for a clean fall.
- Armed and ready: driver off, servo off. Only the ESP32 and the radar draw power.
- Boot: driver off first thing, finger to lock, never rewinds on its own. See "Home at boot" below.
- The machine runs on its own task, so console, page and network updates stay live during a cycle. `stop` works mid-drop and mid-rewind.

## The drop's two rates

FastAccelStepper 0.33.14 has one acceleration value per move, not separate start and stop rates. It does recompute the stop when the acceleration is changed mid-move (`setAcceleration` then `applySpeedAcceleration`). So the drop starts at `dropacc`, and the machine task, every 2 ms, works out how far the stop at `dropdec` needs from the current speed. When the move gets that close, plus a margin of 10 ms of travel and 50 steps, it switches to `dropdec`. The margin matters: switched too late, the library overshoots the end and reverses back to it.

If `dropdec` is set equal to or above `dropacc`, no switch happens and the whole drop uses `dropacc`.

Unit check: one microstep = pi x 50 mm / 1600 = 0.098 mm of line. 1 m/s is about 610 rpm. 100000 steps/s^2 is about 1 g at the barrel.

Drop steps = dropmm / 0.098 mm + the steps the unload actually wound up. `dropmm` can never be set closer than 30 mm to the barrel knot (at most `line` - 70). If a smaller `line` is stored than the drop allows, the drop is cut to fit and says so in the log.

## Limit switch

A 3-pin endstop at the eyelet, pressed by the stop bead when the spider arrives home. Wiring in `02_electrical.md`.

- Off until you turn it on (`limit 1`), so an unwired or backwards switch cannot stop a rewind early. Check it reads right first: the page shows "reads pressed" or "reads open"; press the lever by hand and watch. If backwards: `liminv 1`.
- When on, it is a hard cut-off: any motor move in the rewind direction stops within a few milliseconds of the switch closing, in every state. That includes the 1/12 turn unload at the release; if the switch cuts it short, the log says `unload cut short by the limit switch`.
- Faults it catches, each a strike (three in a row and it stops arming until `clear` or a BOOT press):
  - trips in under a quarter of the expected rewind: line snagged or broke;
  - full rewind runs and it never trips: bead missed it, or it is unplugged;
  - still pressed right after a drop: wiring or `liminv` wrong. That rewind then runs on the step count alone.
- Each cycle's rewind that ends on the switch reports how far the spider dropped, to check against `dropmm`.
- Lost steps on the stop: if that rewind runs more than 20 mm past the drop (allowing one unload for the seat), the log says `lost steps?`. It means the spool got ahead of the motor at the stop and the line's stretch caught the spider. Not a fault on its own; lower `dropdec` or `droprpm` if it repeats.

### Home at boot (V14)

After the lock seat the bead drops off the flap, so the switch reads open with the spider home. That is by design. The firmware remembers, in flash, that the last lock followed a rewind the switch stopped. At boot:

- switch pressed, or that memory says home: no message, ready;
- switch open and that memory says home: log `switch open, spider home from the last lock`, ready;
- switch open and home not known: the page says the spider is not home; rewind and lock by hand. Boot still never rewinds.

Any drop, release, jog, finger move, rewind start, or a stop part way through something forgets home until the next switch-stopped rewind and lock. `status` shows `home=yes` or `home=unknown`.

## Console commands

USB serial at 115200, the web page's Console card, or `tools/console.py`. Replies from either one show on both.

| Command | Does |
|---|---|
| `help`, `status` | list commands; show state, settings, sensor, limit switch, rewind steps |
| `arm`, `disarm` | let the radar fire it, or ignore the radar |
| `drop` | full cycle now (works when disarmed): unload and release, powered drop, settle, rewind, lock |
| `rel` | unload and release only (steps 1 to 3 of the drop): the motor winds up 1/12 turn while the finger swings out, then stays on holding the spider. `jog` lowers it; `off` lets it slide down on the motor's drag |
| `rewind` | rewind only; motor stays on until `lock`; stops at the limit switch |
| `lock` | finger in, seat move onto a tooth, motor off, servo off |
| `jog <n>` | move n microsteps (1600 = one turn), + = rewind direction, motor stays on. Finger out first: if it is not already at the release angle, the release runs (finger out with the 1/12 turn unload), then the jog. Refused winding in with the switch pressed |
| `servo <deg>` | move the finger live, to find angles; it holds there |
| `stop` | halt everything now, abort any cycle, leave the motor powered as it was |
| `off` | motor and servo off |
| `clear` | forget faults and re-arm the cycle |
| `setlock <deg>`, `setrel <deg>` | store finger angles (0 to 180) |
| `line <mm>` | line length from the barrel knot to the stop bead, line straight not pulled (100 to 3000). Refused if it would leave `dropmm` reaching the knot |
| `dropmm <mm>` | how far the spider drops, 100 to `line` - 70, default 620 |
| `droprpm <n>` | drop top speed, 100 to 900, default 500 |
| `dropacc <n>` | drop start rate, microsteps/s^2, 20000 to 400000, default 120000 |
| `dropdec <n>` | drop stop rate, 10000 to 200000, default 60000 (about 0.6 g). Keep low: the motor has to stop the spider |
| `relms <ms>` | finger travel time before the drop starts, 100 to 600, default 250 |
| `rpm <n>` | rewind speed, 30 to 600, default 240 |
| `dir <0/1>` | flip rewind direction |
| `settle <ms>`, `rearm <ms>` | hang time, lockout time |
| `limit <0/1>`, `liminv <0/1>` | limit switch fitted; switch reads backwards |
| `wifi` | where the board is on the network |
| `save`, `defaults` | write settings to flash; reload factory values (not saved) |

- Settings apply immediately; `save` keeps them through power loss. Bad values (out of range, not a whole number) are refused and nothing changes. `dir`, `rpm` and the drop settings are refused while the motor runs.
- **The motor never turns with the finger in** (owner 2026-10-01). `jog` and `rewind` swing the finger out first, with the 1/12 turn unload, unless it is already out; a drop releases before it unwinds. The one exception is the lock's seat move, which lets the spool down onto the finger on purpose.
- Any bench motion (`rel`, `lock`, `rewind`, `jog`, `servo`, `stop`, `off`) disarms the radar so nothing fires with hands in the frame. Send `arm` when done.
- Motion commands are refused while a cycle runs; `stop` and `off` always work.
- Each motion command ends with a `[done] ...` or `refused: ...` line. `tools/console.py` waits for it.

## tools/console.py

Sends commands and prints the replies, then exits. Needs pyserial (`tools/requirements.txt`).

```
python tools/console.py COM13 status "jog 1600"
python tools/console.py dropspider.local status
python tools/console.py COM13 --listen 10
```

Opening the port does not reset the board.

## Rewind math

steps = ((line - 40 mm) / (pi x 50 mm) + 0.75 turn) x 200 x 8

In a cycle the rewind is the drop's steps + 0.75 turn instead, if that is less: the spool is only down as far as the drop went.

The 40 mm is line that stays between spool and eyelet. The 0.75 turn overshoot guarantees the bead reaches the eyelet. With the limit switch on, the rewind stops at the switch instead; without it, the motor slips (skips steps, a short buzz, harmless at 0.6 A) for the rest.

Speed ramps up over 600 steps and down at the end of a counted move. A stop by the limit switch is instant, no ramp down.

## Known limits

- No stall detection: needs the driver's UART line, which the expansion board does not expose.
- Radar UART pins (GPIO16, 17) are wired but unused. Future: read target distance directly instead of OUT.
- The update page and network upload use one shared password from `secrets.ini`. Fine on a home network; not for anything public.
- Static IP address: not yet.

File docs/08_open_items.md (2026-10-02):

# 08 - Open items, risks, verification status

What is proven, what is not, and what could stop the build. Evidence for every closed item is in `commissioning_log.md`.

## Risk raised by the software/electrical team, for the mechanical owner

| ID | Item | Why it matters | How to settle it |
|---|---|---|---|
| M1 | **Confirmed, fixed on paper in Rev C.1, not yet tested.** Mechanical owner agrees: design error. Fix: HF0612 flipped, motor-led drop. See `M1_fix_handoff.md`. Original finding below. A one-way clutch can only let the spool spin free in the same direction the motor drives it | The motor has to drive the spool in the wind-up direction. The spider falls in the opposite direction. A one-way bearing locks in one relative direction and slips in the other, so the direction the motor can drive is exactly the direction the spool can NOT free-spin with the rod still. Same as a bicycle: the pedals drive the wheel forward and the wheel coasts forward, but push the bike backward and the pedals turn. Read that way, either the spool free-falls (commissioning step 7 passes) and then the motor cannot wind it up in either `dir` (step 8 fails both ways), or the motor winds it up and the drop back-drives the motor, which the hard constraints forbid. Reasoned from doc 01, **not tested on hardware** | One minute by hand once the spool is on the rod: hold the rod still and find the direction the spool spins free (the drop direction). Then hold the spool still and turn the rod the other way (the wind-up direction). If the rod slips there too, the clutch cannot wind the spool and doc 01 needs the mechanical owner |
| M2 | Finger cannot release while the spider hangs. Found by the mechanical owner during the M1 rework, **not tested** | The release swing drives the finger tip into the loaded tooth's steep face, so the servo fights the tooth | Rev C.1 release winds the spool clockwise (seen from behind the motor) about 1/12 turn while the finger swings out. Test T3 in `M1_fix_handoff.md` |

## Verified (in the design package)

| Item | How |
|---|---|
| Every STL is watertight (printable solid) | `cad/generate.py` checks on export |
| No part collides with the spinning spool; 2 mm clearance all round | swept-clearance check in `generate.py` |
| Finger tip reaches inside the tooth root | `generate.py` prints tip position |
| Spool body and ratchet print with zero supports | flat faces down, no overhangs |
| Firmware compiles and links (46% flash, 17% RAM) | `pio run`, espressif32@6.7.0 (Arduino core 2.0.16), ESP32Servo 3.0.6, FastAccelStepper 0.33.14, 2026-09-24 |

## Not yet verified (hardware needed)

| ID | Item | Test | If it fails |
|---|---|---|---|
| V2 | Servo angle direction (release = smaller angle) | step 5 | swap `setlock`/`setrel` values |
| V3 | HF0612 press fit in PLA holds without creeping | step 11, then after 20 cycles | CA on the outer ring |
| V4 | Line stretch as the shock absorber (6 lb mono, owner 2026-09-26, elastic dropped): estimated 12 N peak for a 60 g spider if the motor loses grip; snaps at about 27 N. Not tested; a motor-fault drop is never forced on purpose | step 7 | if a knot ever parts, put 150 mm of 2 mm elastic back at the barrel |
| V5 | Motor skipping at the bead stop is short and harmless | step 9 | lower `rpm`, trim overshoot in `config.h`. With the limit switch on, the motor stops at the switch and should not skip at all |
| V6 | Finger lifetime in PLA | step 14 | PETG finger |
| V7 | LD2410C range and through-wall behavior in this house (fallback sensor only since Rev C.1) | step 12 with `sensor 2410` | tune gates; AM312 fallback |
| V9 | Limit switch reads right and stops the rewind at the bead | steps 3b and 9 | `liminv`; move the switch; route its lead away from the motor wires |
| V10 | Limit switch mount. **Designed in Rev C.1:** KW12-3 in the fairlead with a hinged flap (doc 09, `cad/fairlead.py`). CAD-checked: 4.0 mm roller push against 3.4 mm needed, hard stop takes the motor's pull. Inverted install: the same unit as one block under the base (`fairlead_base.stl`, doc 09), same checks pass. Not yet built | doc 09 assembly step 5 by hand, then commissioning step 9 | slide the switch in its slots; reprint the flap |
| V11 | Board joins the home network, page loads, network update works | step 3a, then one `scripts\update_firmware.bat` WiFi update | USB console `wifi`; own network DropSpider-setup at 192.168.4.1 |
| V13 | Top drop speed and stopping ability of the NEMA 11 at 12 V, 0.6 A, with the real spider (estimate: about 500 rpm, stops 60 g or less cleanly) | T4, T5, T7 in `M1_fix_handoff.md` | lower `droprpm` / `dropdec`; lighter spider |
| V14 | **Answered by the fairlead geometry:** after the lock seat the bead drops off the flap, so the switch reads OPEN at rest. Firmware must infer home from the last cycle (switch stop, then seat move), not from the boot reading | commissioning step 10; boot with the spider home | firmware rule, not hardware |
| V15 | LD2450 as the trigger: tracking through the door frame, speed sign, approach-only firing, arrival timing | S1 to S5 in `handoff_sensor_bearings.md` | widen or narrow `doorwidth`, tune `leadms`; `sensor 2410` fallback |
| V16 | Printed fits on the owner's printer after the fit-check fixes: finger on the spline (5.0 drawn), spacers, ratchet over the HF0612 stub, flap on the M2 bolt, cradle grooves | test fit at assembly | open the hole with a drill by hand; adjust the drawn size in code |
| V18 | Inverted install (doc 06 alternative, the owner's plan approved 2026-09-27): device turned over on two steel corner braces, `fairlead_base.stl` under the base, radar fork bolted under the servo end (`ld2450_fork_screw.stl`), five holes drilled in the base. CAD-checked 2026-09-27 (`python cad/inverted.py`: watertight, clears every part including a 52 x 75 x 30 board box, line path clear, flap and switch as doc 09, radar view not blocked by the device). **Not printed, not hung**; the braces and their holes are the owner's | build it, hang it on the bench, run commissioning steps 9 and 12, then walk test S3 (does the radar see the spider?) | radar tilt; the spider-in-view question is open |
| V20 | Finger height on the real spline (was a second V18, renumbered 2026-09-27): plate must cover the ratchet disk by at least 5 mm (spline tip measured about 2 mm short of the ledge) | look edge-on at assembly step 14 | spacer A and shims move the disk |
| V19 | Reinforced fairlead body strength and the flat switch face on a real print; switch mounts with no washers | assembly steps 15 to 15d | 6 walls on that part |
| V21 | Spool stack on the owner's build (2026-10-01): the HF0612 slips a bit, only under more load than the spider's weight (the bearing turns in the printed hole, owner confirmed; he keeps this stack). The slip means the step count drifts, so the limit switch is what homes the spool on every rewind: it must be wired, reading right and turned on (`limit 1`, off by default) before the device is armed; and the finger caught the r 32 shield once the stack was shimmed along the rod; the owner cut about 5 mm off the finger's face, so tooth engagement is less than designed | look edge-on at the lock angle; watch for the spool creeping round the bearing | `docs/handoff_spool_onepiece.md` |

## Closed

| ID | Item | Result |
|---|---|---|
| V8 | Firmware on PlatformIO's current esp32 core (3.x) | Closed by pinning, not by testing 3.x: `platform = espressif32@6.7.0` (Arduino core 2.0.16) builds clean, 2026-09-24. Moving to core 3.x is a deliberate future change, not an accident of a fresh install |
| V12 | Board on COM13 is an ESP32 with 4 MB flash | Closed 2026-09-25: the 30-pin DevKit V1 in use, ESP32-D0WD-V3, 4 MB, read by esptool |
| V1 | ESP32 3.3 V signals drive the driver | Closed 2026-10-01: `jog 1600` gave one smooth turn, no buffer needed (commissioning log) |
| V17 | Fitted servo is a positioning one, not a 360 | Closed 2026-09-27: `servo 90`, `30`, `150` moved and held; the owner's MG90, about 90 degrees of swing (commissioning log) |

## Known limits of Rev C.1

- The owner is building the inverted install on the beam's face (doc 06, V18): CAD-checked, not built. The ceiling install stays documented in doc 06.
- No stall sensing; the expansion board hides the TMC2209 UART pin.
- Static IP address not set yet; DHCP only.
- One shared update password, from `secrets.ini`. Fine on a home network.

## Candidate Rev D items (not started)

- Enclosure for the controller board.

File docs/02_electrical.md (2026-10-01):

# 02 - Electrical

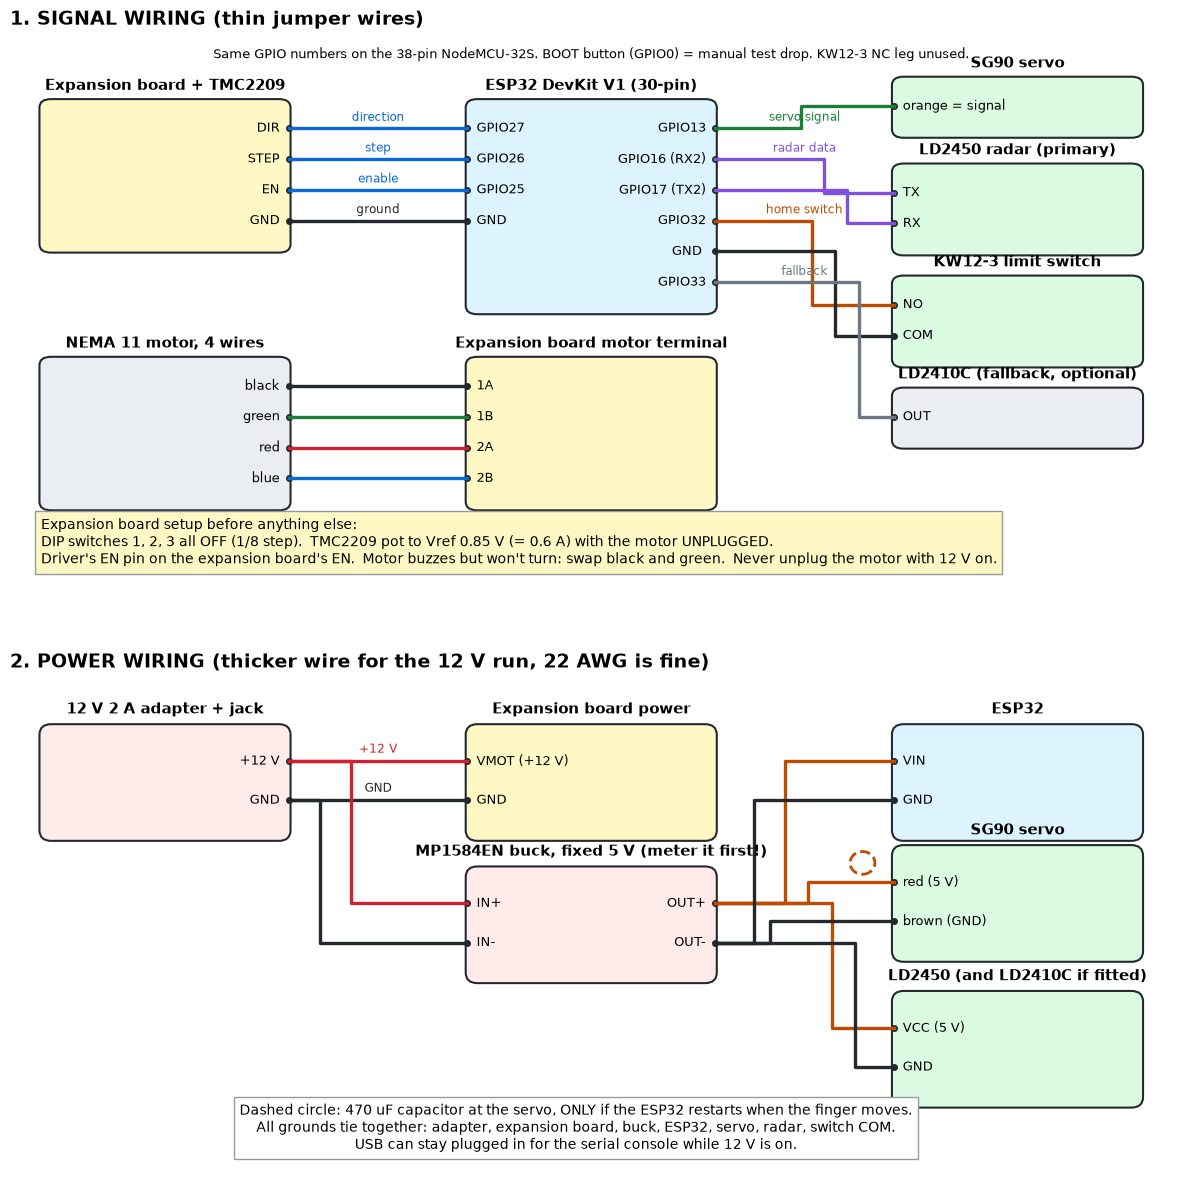
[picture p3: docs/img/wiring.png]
Wiring


## Pin map, 30-pin ESP32 DevKit V1 (board in use)

Board: 30-pin ESP32 DevKit V1, ESP-WROOM-32 module, CP2102 USB chip, PlatformIO board `nodemcu-32s`. The 38-pin NodeMCU-32S uses the same GPIO numbers and works unchanged; go by the name printed beside each pin, not its position. The 5 V input pin is marked VIN on the 30-pin board and 5V on the 38-pin.

| ESP32 pin | Goes to | Direction | Notes |
|---|---|---|---|
| VIN | buck OUT+ (5.0 V) | power in | Do not feed 12 V here |
| GND (any) | common ground | - | All grounds tie together |
| GPIO27 | expansion board DIR, S row | out | Rewind direction set in firmware |
| GPIO26 | expansion board STEP, S row | out | One pulse = 1/8 motor step |
| GPIO25 | expansion board EN, S row | out | LOW = motor powered, HIGH = coils off (free) |

D27, D26, D25 sit side by side on the ESP32 header in the same order as the expansion board's DIR, STEP, EN columns, so one 3-wire ribbon goes across straight (changed 2026-10-01; before then STEP was GPIO25, DIR 26, EN 27).
| GPIO13 | SG90 orange | out | Not GPIO14: 14 pulses during boot and twitches the finger |
| GPIO33 | LD2410C OUT (fallback only) | in | HIGH = someone present. Firmware adds a pull-down. Used only with `sensor 2410` |
| GPIO32 | KW12-3 limit switch NO leg (COM to GND) | in | In the fairlead (doc 09). Pressed = bead lifting the flap. Firmware adds a pull-up |
| GPIO16 (RX2) | LD2450 TX (yellow wire) | in | Primary trigger, UART2 at 256000 baud |
| GPIO17 (TX2) | LD2450 RX (green wire) | out | Primary trigger |
| GPIO0 | on-board BOOT button | in | Press = manual test drop. Not on the 30-pin header; nothing to wire |
| GPIO2 | on-board LED | out | Slow blink = armed and ready |

## Driver: BIGTREETECH TMC2209 V1.3 on the A4988/DRV8825 expansion board

- Plug the driver in with its **EN** pin on the expansion board's **EN** position. Backwards destroys it on power-up.
- DIP switches 1, 2, 3 all **OFF**. On a TMC2209 that is 1/8 microstep (each STEP pulse moves 1/8 of a full step) and leaves the UART pin (the driver's serial setup line, unused here) alone.
- Current: turn the driver's pot until the voltage from the pot's metal top to GND reads **0.85 V** (= 0.6 A, 90 percent of the motor's 0.67 A). Do this with 12 V on and the **motor unplugged**. Factory default is about 1.2 V, too high for this motor.
- STEP/DIR/EN only. UART is not wired; the expansion board does not bring that pin out.
- The expansion board's DIR, STEP and EN columns each have three pins, S, V, G. The ESP32 wire goes on **S** (signal). One wire from an ESP32 GND to any **G** (the G pins are all joined). Leave every **V** empty.

## Power

| Rail | Source | Loads | Worst case |
|---|---|---|---|
| 12 V | 12 V 2 A wall adapter | driver/motor, buck input | about 0.6 A while rewinding (about 3 s per scare), about 0.05 A idle |
| 5 V | MP1584EN mini buck, fixed 5 V (not adjustable). Meter its output on 12 V **before** connecting anything | ESP32 (0.25 A peak, WiFi on), SG90 (0.7 A stall peak), LD2450 (about 0.1 A), LD2410C if fitted (0.08 A) | about 1 A peak; the MP1584EN is comfortable to about 1.5 A |

- 470 uF 16 V electrolytic across the servo's red and brown: **only if** the ESP32 restarts when the finger moves (the page's "Running for" clock resets). A micro servo moving for a fraction of a second on the buck's output does not normally need it. If fitted: at the servo end, stripe to GND.
- Idle draw between scares is a few watts at most: driver disabled, servo detached, radar and ESP32 on.
- USB can stay connected to a PC for the console while 12 V is on.
- Ceiling install: run 12 V up with a 5.5 x 2.1 mm DC extension cable. Keep the adapter at the outlet, never at the ceiling.

## Logic-level check (V1, required before first motor run)

The expansion board powers the driver's logic side from its own 5 V regulator, and the ESP32 drives STEP/DIR/EN at 3.3 V. Most TMC2209 boards accept that, but it is not guaranteed.

Test: with the motor connected, run `jog 1600` from the console. The motor must make exactly one smooth turn. Then `jog -1600`, one turn back.

If it stutters, misses, or does nothing while the driver clearly holds (shaft stiff): add a 74AHCT125 (or any 5 V buffer with 3.3 V-compatible inputs) powered from the 5 V rail between ESP32 and expansion board on STEP, DIR, EN. Wiring: ESP32 pin to buffer input, buffer output to expansion board, buffer enable pins to GND.

## Motor wiring

STEPPERONLINE NEMA 11, 11HS12-0674S (0.67 A, 5.6 ohm per coil): black (A+) + green (A-) = coil A, red (B+) + blue (B-) = coil B. Meter check: black to green and red to blue each read about 5.6 ohm; any other pair reads open. Black to 1A, green to 1B, red to 2A, blue to 2B. The leads come bare: put a female jumper end on each (half of a female-to-female jumper, joint soldered or twisted and covered, joints staggered) and push them onto the expansion board's motor pins. If the motor buzzes but will not turn, swap black and green. Never plug or unplug the motor with 12 V on.

## Limit switch wiring (KW12-3 in the fairlead)

The KW12-3 roller switch is built into the fairlead (doc 09). On rewind the stop bead lifts a hinged flap, the flap's tail presses the roller, and the firmware stops the motor the moment it closes.

Bare switch, three legs: **COM to GND, NO to GPIO32, NC unused.** No power wire. On the switch in hand, from the lever's hinge end the legs are COM, NO, NC (read off the part 2026-09-25). Meter check: the leg that beeps to one other leg at rest and to the third with the lever held is COM.

Open = HIGH, pressed = LOW with the firmware's pull-up. Check with the web page by lifting the flap by hand; if it reads backwards, `liminv 1`. Then `limit 1` turns it on. Keep the lead away from the motor wires, or twist its signal and ground together. Inverted install (doc 06): the switch and the radar sit under the base and the board on top, so their leads run round the base's far (servo) end, about 15 cm for the switch and 25 cm for the radar, tied clear of the spool.

By design the switch reads **open** at rest after the lock seat (doc 09, V14): the seat move lets the bead drop off the flap.

## Sensor wiring

**LD2450 (primary):** 5 V, GND, TX to GPIO16, RX to GPIO17. The owner's cable (2026-10-01), colours at the sensor: **red 5 V, black GND, yellow TX (to GPIO16), green RX (to GPIO17)**. TX goes to RX and RX to TX: yellow is the sensor's transmit, so it lands on the ESP32's receive. 4-pin, 1.25 mm plug at the sensor. No OUT pin. See `03_sensor.md`.

**LD2410C (fallback, optional):** 5 V, GND, OUT to GPIO33 (3.3 V output, goes straight in). Used only with `sensor 2410`.

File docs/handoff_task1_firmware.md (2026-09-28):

# Handoff: task 1, bench tests T1 to T8 of the Rev C.1 motor-led drop

What this is for: fix the spool-to-flap length for the inverted install, then run bench tests T1 to T8 with the owner, fix what fails, and log every result in `docs/commissioning_log.md`. Future work only; what is already done is in `CHANGELOG.md`.

## Ground truth first

This file is a pointer, not a record of truth. The local repo wins. If anything here disagrees with a file, the file is right and this handoff is stale: say so out loud.

Staleness check, run first:

```
git log -1 --oneline                                     # where the repo is now
git log -1 --oneline -- docs/handoff_task1_firmware.md   # when this handoff was last true
```

Same hash: nothing landed since. Different: re-run the checks below before trusting them.

## Before you start: run these checks

| Check | How |
|---|---|
| Rev C.1 is on the board | `python tools\console.py dropspider.local status`: boot line "Rev C.1 ready"; `help` lists `dropmm`, `droprpm`, `dropacc`, `dropdec`, `relms` |
| The servo is a positioning one, not a 360 | `docs/commissioning_log.md` has a V17 PASS row; if not, `servo 90`, `servo 30`, `servo 150` with nothing on the spline: it must move and hold |
| Finger angles stored | `status` shows `setlock` and `setrel`; the log has the owner's values. Recheck them with the ratchet on the rod in T3 |
| The mechanism is assembled on the bench: spool with the HF0612, ratchet, finger, motor, fairlead or `fairlead_base` with flap and KW12-3, line and bead | ask the owner, one line |

## Read first

1. `CLAUDE.md` (repo root): hard constraints. The ones that bite here: motor-led drop, never drop with the driver off; release under load winds clockwise (seen from behind the motor) about 1/12 turn while the finger swings out; servo on GPIO13; boot never auto-rewinds and EN goes HIGH first in `setup()`; armed idle = driver off, servo detached.
2. `docs/M1_fix_handoff.md`: section "Bench tests" is T1 to T8; "Firmware spec" is what the firmware on the board implements.
3. `docs/04_firmware.md`: firmware layout, console commands, update paths.
4. `docs/09_fairlead_switch.md`: V14, the switch reads OPEN at rest after the lock seat by design; home comes from the last cycle.
5. `docs/handoff_sensor_bearings.md`, "Inverted install", item 4: the spool-to-flap length.

## The work, in order

1. **Spool-to-flap length.** `include/config.h` `SPOOL_TO_EYELET_MM` is 40 (its comment still says braid; the line is 6 lb mono). The owner is building the inverted install, where it is about 72 mm with fairlead v2 (doc 09). Set it to 72, or make it a setting, and fix the comment. Check the factory `dropmm` (620) against an inverted line of about 636: the limit is line minus that length minus 30, so it must come down or the page refuses the new line. Build (`pio run`), flash over WiFi (`pio run -e ota -t upload`), report the observed output only.
2. **Bench tests T1 to T8 with the owner.** Before any motor or servo move, ask him to confirm hands and line are clear, and wait for his yes. Re-set the switch click point with its slots before T2 (flap lifted about 2 mm must click). Log each test, pass or fail, with what was seen. A test not run is written as "not run", never as a pass.
3. **Fix what fails**, one change per commit, and re-run the failed test.
4. **Close the open items the tests settle** in `docs/08_open_items.md` (V1, V2, V9, V13, V14), each with the log row as evidence. Update doc 04 and the web help text for anything changed.
5. **Finish:** changelog line, remove this task's roadmap lines, move this file to `docs/retired/`.

## Tests

T1 to T8 as written in `docs/M1_fix_handoff.md`, section "Bench tests", each logged in `docs/commissioning_log.md`.

## Done when

T1 to T8 are each logged as PASS on the bench with the spool, clutch, finger and switch fitted.

## Rules for the session

- Owner is Joe. Replies are barebones, verdict first, plain English, no excuses; see his global CLAUDE.md.
- He never types commands: the session runs them. He can double-click a .bat, change an app setting, look and answer in one line.
- One task per commit, files staged by name.
- Verify before claiming: "works" only after running it and reading the output.

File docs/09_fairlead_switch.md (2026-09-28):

# 09 - Fairlead and limit switch (Rev C.1)

Replaces `line_guide.stl`. The bracket is unchanged and reused. Closes open item V10 (switch mount).
Source: `cad/fairlead.py`, pulled into `cad/generate.py`. Regenerate STLs and images with `tools\regen_cad.ps1`.

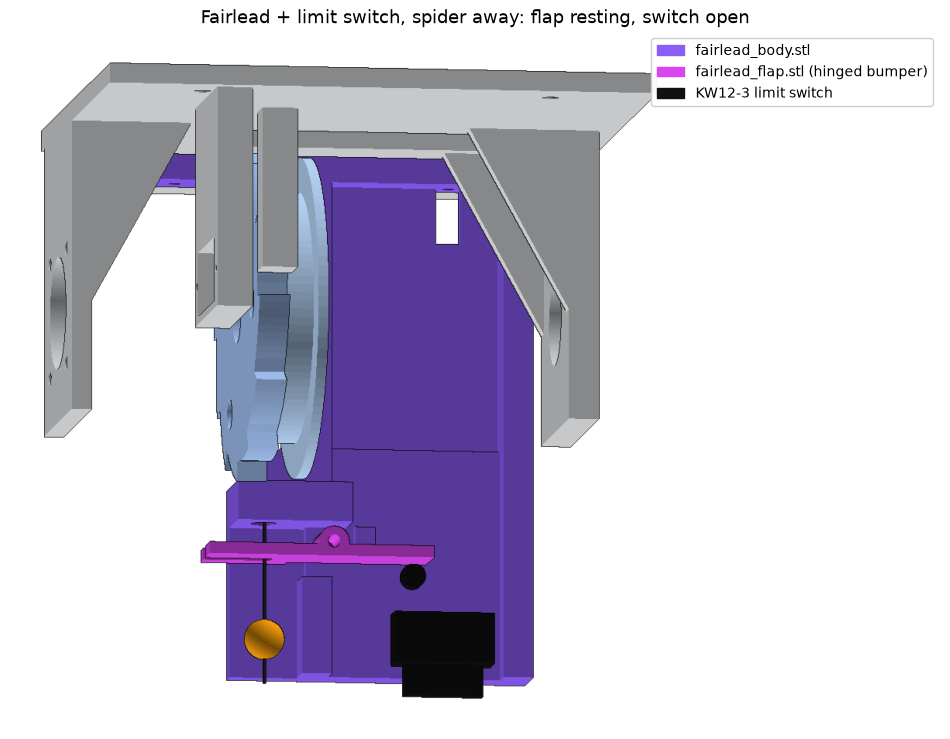
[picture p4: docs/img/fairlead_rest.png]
Spider away

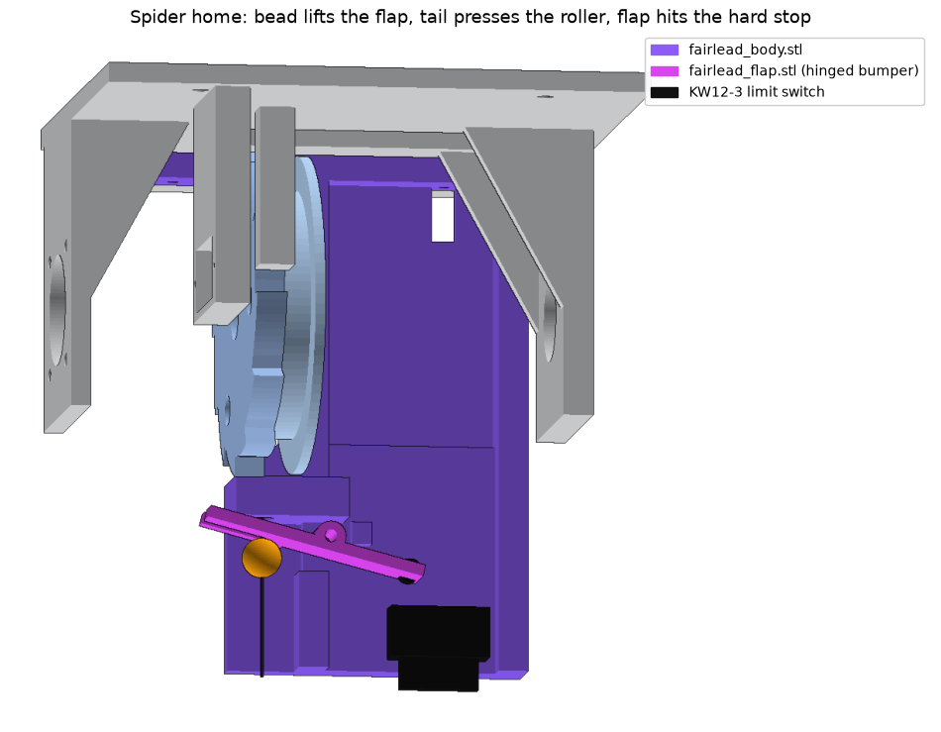
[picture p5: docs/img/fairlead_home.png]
Spider home

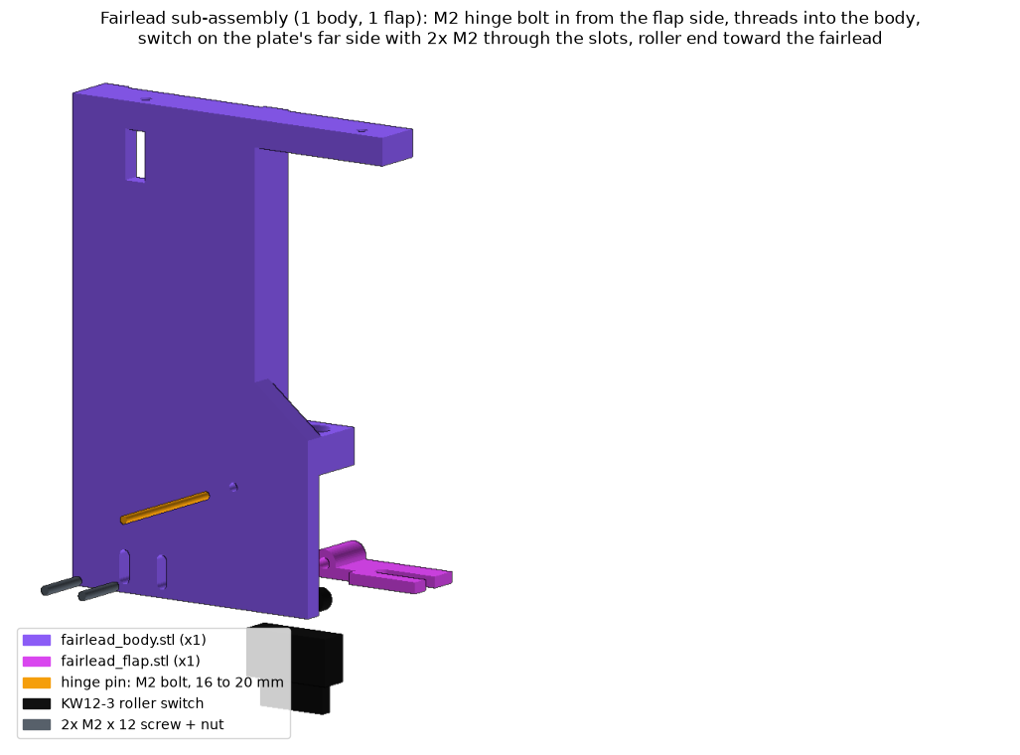
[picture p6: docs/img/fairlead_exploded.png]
Sub-assembly


**Quantity: one fairlead body and one flap per build** (print a spare flap if you like).

## What it is

| Part | Job |
|---|---|
| `fairlead_body.stl` | Screws to the pad in the old line guide's spot (2x M3 countersunk from the ceiling side). Holds the fairlead, the hinge, the hard stop, the rest stop, and the switch plate |
| Fairlead (in the body) | Smooth, flared bore the line runs through: 9 mm wide at the top (spool side), 3.2 mm at the narrowest, 6 mm at the bottom. No sharp edges for the line to saw on. Centered on the spool's line channel |
| `fairlead_flap.stl` | Hinged bumper below the fairlead. The line passes loosely through an open slot, so it can be slipped in after the bead and swivel are tied. The prong on the switch side of the slot is 3.8 mm wide (was 1.2, too thin, owner 2026-09-27) |
| KW12-3 roller switch | Screws to the switch plate. Its roller rests just under the flap's tail |
| Hinge pin | M2 bolt, 16 to 20 mm: free in the flap, threads itself into the body |

## How it works

1. Spider away: the flap hangs level on its rest stop. The switch is open.
2. Rewind: the 8 mm stop bead rises and lifts the flap's free end. The flap pivots; its tail swings down onto the switch roller.
3. The switch clicks after about 2.3 mm of bead travel (2.6 mm at the roller). The firmware stops the motor.
4. If the motor keeps pulling, the flap lands flat against the fairlead's underside (the hard stop) after 3.3 mm of bead travel. The motor's pull goes into that face, not into the switch or the hinge pin.
5. Spider drops: gravity and the switch spring return the flap to its rest stop.

Measured in CAD: hard stop at 14.75 degrees; roller pushed 4.3 mm at the stop, 0.3 mm gap at rest, so about 4.0 mm of actual push against the switch's 2.6 mm to click plus 0.8 mm minimum overtravel. No collisions with the spool, bracket, servo or motor; 2 mm clearance to the spinning spool.

## Print

| File | Orientation | Settings |
|---|---|---|
| fairlead_body.stl | as exported (flat side down, 17 mm tall) | PLA, 4 walls, 40% gyroid, **no supports** (the bore and slots bridge) |
| fairlead_flap.stl | as exported (flat side down) | PLA or PETG, 4 walls, 100% rectilinear, brim 5 mm |

One flap is needed; a second is a spare.

## Assemble

1. Clean the fairlead bore with a 3 mm drill turned by hand. Run a scrap of the line through it; it must slide without catching. Sand the top flare smooth if it feels rough.
2. Fit the switch to the plate: **roller end toward the fairlead** (toward the spool), body on the side away from the plate's flat back. Two M2 screws through the plate's slots and the switch, nuts on the switch side. Leave them finger-tight.
3. Push the flap's knuckle into the gap below the fairlead and line up the holes. Drive an M2 bolt (16 to 20 mm) in from the flap's outer side: free through the flap (2.5 mm hole; drill it by hand if it drags), threading itself into the body. Stop before the head clamps the flap; it must swing down under its own weight.
4. Flap level on its rest stop: slide the switch up in its slots until the roller just touches the flap tail, then back it off about 0.3 mm (a piece of paper's thickness). Tighten.
5. Check by hand: lift the flap's free end. Click at about 2 mm; flap stops flat against the fairlead a moment later. Let go: it drops back, switch opens.
6. Screw the body to the pad: 2x **M3 countersunk (flat-head) screws, 8 to 10 mm**, put in from the ceiling side down through the x = -32 pad holes, heads flush with the ceiling face, cutting their own thread into the fairlead's rail (2.5 mm pilots). No glue (owner 2026-09-26). The pad holes need a 90 degree countersink so the heads sit flush: new bracket prints have it; on an already printed bracket, twist an 8 mm drill bit by hand in each of the two holes from the ceiling side until a screw head sits flush or just below.
7. Thread the line from the spool down through the fairlead, then slide it into the flap's slot from the free end. Bead, swivel, spider below as before.

## Inverted install: `fairlead_base.stl` and `fairlead_flap_inv.stl` (v2, 2026-09-28)

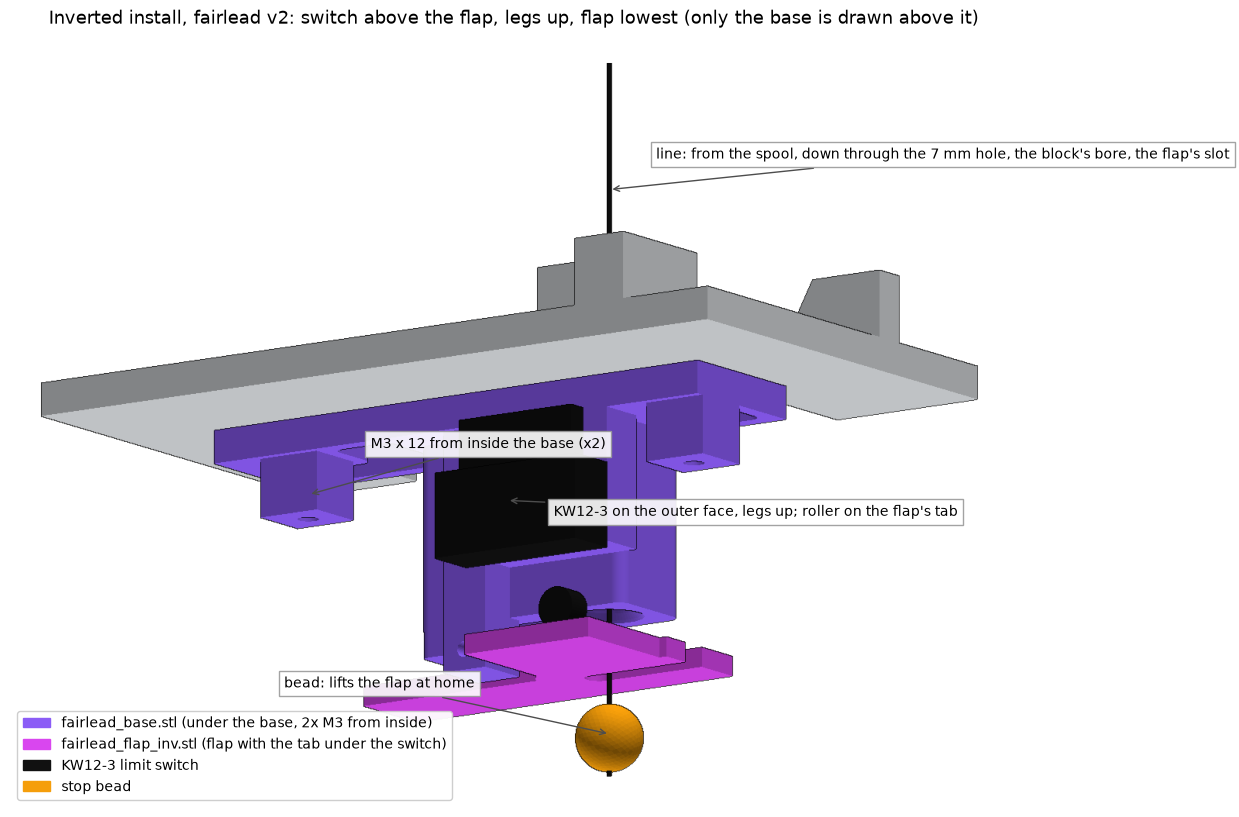
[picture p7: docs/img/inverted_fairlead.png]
Fairlead v2


Owner's edits the same day: the line bore widened (4.0 mm throat, was 3.2; mouths 7 mm at the base and 9 mm at the flap, each flare 6 mm long); the switch plate solid with two self-tapping M2 holes instead of slots and nuts; the rest pad shortened 1.25 mm, so the flap hangs at 9.5 degrees at rest (was 1.75) and the roller sits about 3 mm clear of the tab until the bead lifts it.

Owner's redesign ask, 2026-09-28: the switch faces outward, its legs and wires point up toward the spool instead of hanging under the flap, and the flap is the lowest point. So the switch now sits above the flap on the block's outer side, legs up, and its roller rests on a tab added to the flap's free-end side. The bead lifts the free end; the tab lifts the roller. Source `fairlead_base()` and `flap_inv_local()` in `cad/inverted.py`. Stacking the switch above the flap takes about 30 mm under the base, so the flap hangs 32 mm under it (v1: 15 mm, with the switch hanging to 43).

Checked in the model 2026-09-28 (`python cad/inverted.py`): block and flap watertight; mounting face one plane; clear of every part (braces, radar, board box); line path clear through the base hole, the bore and the flap slot; hard stop 14.75 degrees; roller pushed 4.03 mm past touching (needs 3.4, same as v1); lowest points below the base: flap 37.3 at rest, block 32.7, switch 30.5; switch legs end 4.1 mm under the base; 2 mm clear of the spool; screw heads clear. Not printed or fitted yet.

| Step | What to do |
|---|---|
| Print | `fairlead_base.stl` (mounting face on the bed, 33 mm tall, no supports) and `fairlead_flap_inv.stl` (prints flat like the old flap). The old `fairlead_flap.stl` does not fit this block: it has no tab |
| Holes in the base | Same as before: 7 mm at x 25, z 45 (the line), 3.4 mm at x 32, z 28 and z 83 (block screws). Drawing `cad/bracket_footprint_inverted.svg`, 1:1 |
| Switch | KW12-3 on the block's outer face (the side away from the rod), lever and roller DOWN, legs UP toward the base. 2x **M2 x 12 screws** through the switch, threading straight into the plastic (no nuts, no slots: the switch position is fixed). Hole centres 6.5 mm from the switch plate's free edge (its top as printed) |
| Wires | Solder before mounting. The legs end about 4 mm under the base: lead the wires sideways off the legs, then round the base's far end to the board |
| Flap | M2 bolt, 20 mm, in from the rod side through the flap's knuckle and threaded into the hinge boss, not clamped. The tab goes under the roller |
| Screw on | 2x **M3 x 12** from inside the base (heads on the device side) into the block's 2.5 mm pilots. Flat face against the base's outer face |
| Line | From the spool's servo side down through the base hole, the bore, then the flap's slot |
| Check | Lift the flap's free end by hand: click at about 2 mm, stops flat against the block. Let go: it drops to its rest stop and the switch opens |

Heights change with v2: the bead at home sits about 196 mm below the ceiling (v1: 179), so the retracted spider hides behind a 10 in beam only if it is 28 mm tall or less, and the line between the spool and the flap is about 72 mm (v1: 55). Line length = (ceiling - 196) - (rest height + spider height + 30) + 72.

## Wiring

Bare KW12-3, three legs: COM to GND, NO to GPIO32, NC unused. Firmware pull-up: open = HIGH, pressed = LOW. Check with the web page; `liminv` if backwards.

## Known effects on other items

- **V14, answered by the geometry:** after the lock seat move lets the spool down up to 1/12 turn (about 13 mm of line), the bead drops off the flap and the switch reads **open** at rest. The firmware must not treat "open at rest" as "spider not home". Suggested rule: the last cycle ended with a switch stop, then a seat move, then idle = home.
- Ceiling install: the device now hangs about 36 mm lower (switch at y 112 vs old guide at y 76). Still hidden above the door head per doc 06 at 8 ft ceilings.
- Spider legs wider than about 50 mm may touch the switch at the top. Trim legs or angle them down.

## Unverified

- The KW12-3's operating point is taken from the owner's datasheet (2.6 mm pre-travel, 0.8 mm overtravel, 0.7 N). The slotted holes cover about plus or minus 2.5 mm of error.
- The M2 hinge bolt loosening over a season: a drop of threadlocker or CA on its thread in the body.
- Line wear in the PLA fairlead. Swap for a new print if a groove appears.

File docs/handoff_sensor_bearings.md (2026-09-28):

# Handoff: task 2, LD2450 radar as the trigger

From the mechanical owner to the software/electrical team, written 2026-09-24. Future work only; what is already done is in `CHANGELOG.md`.

**Before you start:** T1 to T8 in `M1_fix_handoff.md` must pass. Check: `docs/commissioning_log.md` has a PASS row for each.

## 1. Sensor: switch the trigger to the HLK-LD2450

### Decision

The owner already has an LD2450. It becomes the primary trigger. The LD2410C is the fallback on GPIO33 (`sensor 2410`), fitted only if a named test fails; it is not fitted today. No purchases.

### Why

The prop only works if the spider lands as the person reaches the doorway. The LD2410C fires on anyone moving inside its range, in any direction, at a fixed distance. The LD2450 reports each person's X and Y position and speed, so the firmware can fire only on people walking toward the door and time the drop to their predicted arrival.

Owner concern raised: "mmWave can be finicky without a clear visual picture." Answer: the LD2450's app shows each person as a moving dot on a map, which gives that picture. Reported user experience, researched 2026-09-24:
- A Home Assistant user powered an LD2450 from 5 V only, connected over Bluetooth, and saw himself moving and standing in the app right away, before wiring it to anything (community.home-assistant.io).
- Complaints that HLKRadarTool is complicated and unintuitive, raised by a sensor maker to Hi-Link, are about the LD2410C's per-gate number entry (screek.io).
- LD2450 zones in the app are drag-and-drop boxes (Apollo Automation docs). We do not use them; see below.
- The module has no external antenna; phone Bluetooth works only within a few feet (Apollo docs).
- ESPHome requires LD2450 firmware V2.02.23090617 or later; the app can update it (esphome.io).
- Weak at people standing still beyond about 2 m; it is a tracker (atomic14.com). Irrelevant: we only want walkers.

**No calibration is required.** The LD2450 streams target data over UART from power-up. The app is optional: live view and firmware update.

### Hardware facts

- 4 pins: 5 V, GND, TX, RX. No OUT pin. Connector is 4-pin, 1.25 mm pitch; check the owner has the cable.
- UART 256000 baud, 8N1, hardware UART only. About 10 frames per second, up to 3 targets, X/Y/speed in mm and cm/s per the Hi-Link protocol (confirm units against the library you pick).
- Field of view about plus or minus 60 degrees horizontal, 35 vertical, range about 6 m.
- Wiring: LD2450 TX to GPIO16 (UART2 RX), RX to GPIO17 (UART2 TX). On the 30-pin ESP32 DevKit V1 in use they are the pins printed RX2 and TX2.

### Firmware spec

1. Before writing a parser, find an existing Arduino or ESP-IDF LD2450 library. Name it, check it builds on espressif32@6.7.0, and say whether you use it and why. Known reference implementations: ESPHome's native `ld2450` component, and the GitHub project PeterkoCZ91/HLK-LD2450-security (has a tested parser with unit tests). Check licenses before copying.
2. New setting `sensor` = `2450` (default) or `2410`.
3. Trigger rule, all must hold for 2 consecutive frames, only while armed and idle:
   - |X| < `doorwidth` / 2 (default `doorwidth` 1000 mm)
   - approaching faster than `approach` (default 0.3 m/s). Confirm the speed sign convention on the bench and put it in a constant.
   - Y / speed < `leadms` (default 750 ms)
4. Clear (for re-arm): no target inside the door-width window with Y under 3 m, for 2 s.
5. Settings in NVS, console, web page, with range checks: `sensor`, `doorwidth` (400 to 2000 mm), `approach` (0.1 to 1.5 m/s), `leadms` (200 to 2000 ms).
6. Web page: live readout of up to 3 targets (X, Y, speed), and a "would trigger now" indicator, for bench tuning.
7. Radar data loss: if no valid frame for 1 s, log a fault and fall back to the LD2410C if `sensor` allows, else stay disarmed.
8. Do not send zone or region commands to the sensor. Leave its built-in area filter off so the firmware sees every target.

### Tests (log as S1 to S5 in `commissioning_log.md`)

| # | Test | Pass |
|---|---|---|
| S1 | App check: firmware version, walk toward the door | version at or above V2.02.23090617; dot tracks through the frame |
| S2 | Live readout while walking toward, away from, and across the door | sign of speed matches direction; X near 0 at the door center |
| S3 | Walk in at normal pace, 10 times | fires every time; spider arrives as you reach the doorway |
| S4 | Walk away, walk past across the hallway, stand still in the window | no trigger |
| S5 | Unplug the radar's TX wire while armed | fault logged within 1 s; fallback per setting |

### Inverted install: four things the firmware must handle (added 2026-09-28)

The owner is building the inverted install (doc 06, V18): the device turned over on two steel corner braces on the porch beam's inside face. The mechanism, the winding sense, `dir` and the switch logic do not change. These four things do. Numbers from `cad/inverted.py` and doc 06; none of them has been seen on real hardware yet.

1. **Radar placement and axes.** The LD2450 hangs in its cradle under the base at the servo end, about 154 mm out from the beam's face, looking back toward the beam and 50 degrees down (55 to 60 if the walk test asks; the cradle clears to 65). People approach from outside, under the beam, toward the radar. Its X axis runs along the rod, which is parallel to the beam, so X is across the walkway, and the line falls at about X = 0. Which way is +X depends on which end of the device the owner puts where. Do not hard-code the sign: add a setting (for example `xflip`, 0 or 1) or confirm it in S2 and store it. The radar sits about 2.28 m up and tilted, so Y is not the floor distance to the doorway; tune `leadms` and the clear distance on the porch, not on the bench.
2. **The spider is inside the radar's view.** Retracted it hangs a few cm below the base and about 37 mm toward the beam from the radar, near X = 0 at short range; dropped, it hangs near the lower edge of the view. It moves during the drop and the rewind and swings after. As written, rule 4 (clear = no target in the window under 3 m for 2 s) could see the spider as a person and hold the device in "waiting for the doorway to clear" after every scare. Design for it: in S2, read the spider's X, Y and speed on the live readout at rest, dropped and swinging, then exclude it (for example a `minrange` setting below which targets are ignored, or ignore targets in a small box around the line during the cycle and for a few seconds after). Check the exclusion does not also hide a person standing in the doorway.
3. **Aluminum blocks the radar.** At 24 GHz, aluminum siding or trim stops the signal completely, however thin. If the beam is clad, the radar sees people only once they are under the beam's bottom edge, and the flat metal can bounce back phantom targets or jumpy positions. Keep the 2-consecutive-frame rule; do not loosen it to cure late firing. The owner's fix is a steeper tilt.
4. **Line between the spool and the flap is longer.** `include/config.h` has `SPOOL_TO_EYELET_MM 40.0f` (its comment still says braid; the line is 6 lb mono). Doc 06 gives 45 mm for the ceiling install and about 72 mm for the inverted one with fairlead v2 (doc 09, 2026-09-28). With 40 the drop-distance limit (`dropMmMax()` = line - 40 - 30) lets the spider stop 15 mm closer to the barrel knot than the 30 mm margin intends, and the rewind estimate in `machine.cpp` is 15 mm short (the 0.75-turn overshoot and the limit switch cover that). Also: the factory `dropmm` 620 only fits the old 720 line; the inverted line is about 636, so the page refuses the new line until `dropmm` is lowered (the build guide tells the owner to do that first). Fix: make it 72 (fairlead v2, 2026-09-28, doc 09), or a setting, and check the factory `dropmm` fits the inverted line. This one bites task 1's bench tests too, not only the radar work.

### Docs yours after the firmware lands

`02_electrical.md` pin map and wiring picture, `04_firmware.md`, `07_commissioning.md` step 12, web help text, and the build guide's radar rows (sections 09, 10 and 12, now marked AFTER TASK 2).

### Finish

Changelog line, remove this task's roadmap line, close V15 in `08_open_items.md` with the S1 to S5 log rows, move this file to `docs/retired/`. Bearing care, formerly section 2 here, is reference and lives in `01_mechanical_design.md`, "Bearing care".

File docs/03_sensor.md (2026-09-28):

# 03 - Sensor

Rev C.1. Decision date 2026-09-24. Details and sources in `handoff_sensor_bearings.md`.

## Choice: HLK-LD2450 (primary), HLK-LD2410C (fallback), both already owned

| | LD2450 (primary) | LD2410C (fallback) | PIR, e.g. AM312 (not owned) | Ultrasonic HC-SR04 (not owned) |
|---|---|---|---|---|
| What it reports | X and Y position and speed of up to 3 moving people, about 10 times a second | one yes/no presence line, plus distance over serial | yes/no when a warm body moves across its view | distance to whatever is straight ahead |
| Can it tell approaching from leaving or passing | **yes** | no | no | only by watching distance shrink |
| Can it time the drop to the person's arrival | **yes** (distance divided by speed) | no, fixed trigger distance | no | roughly |
| Setup | none required; optional app for a live map and firmware update | range zones ("gates") set in the app | aim it | aim it, set one distance |
| Wiring | 4 pins: 5 V, GND, TX, RX. **No OUT pin** | 5 pins incl. OUT | 3 pins | 4 pins, 5 V echo needs a resistor divider |
| Connector | 4-pin, 1.25 mm pitch plug | 2.54 mm header | | |
| Weakness | poor at people standing still (irrelevant here) | fires on anyone moving in range, both directions | pets, heat vents, passers-by | narrow beam, soft clothing |

## Wiring

| Sensor pin | ESP32 |
|---|---|
| LD2450 5V | 5 V rail |
| LD2450 GND | GND |
| LD2450 TX | GPIO16 (UART2 RX) |
| LD2450 RX | GPIO17 (UART2 TX) |
| LD2410C OUT (fallback, may stay connected) | GPIO33 |

UART2 at 256000 baud, 8N1. Hardware UART only.

## Placement

- **On the device**, in `ld2450_cradle.stl`, which tilts on one M3 bolt between the ears of `ld2450_fork_screw.stl`, bolted under the bracket's servo end (+x) with 2x M3: ceiling install, countersunk from the ceiling face, heads flush, nuts on the fork, holes drilled at x 68, z 45 and z 79; inverted install, see doc 06. No glue (owner 2026-09-27). Install (ruled by the owner 2026-09-26): under a **porch ceiling, behind the porch overhang's front beam**. People walk in from outside toward the porch, so the servo end, with the radar, points **out from under the porch** toward them. The beam hides the device from them.
- **Orientation, from Hi-Link's manual (section 7, figure 6):** module standing upright, long edge vertical, **antenna side against the cradle's face plate** (two big windows, so it looks out mostly through air), **pin-header side open at the back**, header end at the bottom. The face plate faces out toward the approach. The cradle sets this. Its left-right reading (X) then runs across the walkway, its distance reading (Y) out along it. Confirm on the bench: walk left to right in front of it; X must change, Y stay steady. If Y changes instead, the board is in sideways.
- **Tilt:** set on site, 0 to 50 degrees down, by loosening the M3 nut, swinging the cradle and tightening (every angle in that range is checked clear in `cad/sensor_mount.py`). For the owner's porch (beam 10 in deep, device 12 in behind it) start at 50 degrees: the beam blocks rays shallower than about 45 degrees (doc 06). The device holds it about 2.3 m up, over Hi-Link's recommended 1.5 to 2 m, so the tilt aims the beam at people 1 to 3 m away. The radar must also see out past the porch's front beam: that depends on the porch's ceiling height, the beam's depth and how far behind it the device hangs, not yet measured. Estimate, checked only by test S3 with the live readout. Y is then the slanted distance, a little longer than the floor distance; the arrival timing (`leadms`) absorbs that.
- **Which way up:** the board slides up into the cradle's grooves from the open bottom end, antenna side toward the face plate, **header end last** so the headers end up at the bottom; it stops against the top block and a small zip tie round the cradle's bottom end holds it (no glue, owner 2026-09-27). Headers plus dupont plugs (24 mm deep) clear everything at every tilt from 30 to 60 degrees that way; at the top end they would hit the bracket above 40 degrees.
- **Back of the sensor:** the manual warns it also sees a little through its back. The dropping spider hangs about 95 mm behind it (line at x = -25, radar near x = 70). The firmware lockout after a scare covers that; if the falling spider ever retriggers it, a piece of kitchen foil on the cradle's back plate (not touching the pins) cuts it down.
- Keep ceiling fans and moving curtains out of its view; they show up as targets.

## Trigger rule (firmware)

Fire when any target:
1. is inside the door width: |X| under `doorwidth`/2 (default 500 mm each side),
2. is approaching: speed toward the sensor above `approach` (default 0.3 m/s; sign convention confirmed on the bench),
3. will arrive soon: Y divided by speed under `leadms` (default 750 ms, about release plus drop time),
4. for 2 frames in a row.

Re-arm: existing lockout, then no target inside the window for 2 s.

Why lead time instead of a fixed distance: a fast walker triggers earlier, a slow one later, so the spider lands at the doorway for both.

## One-time app check (HLKRadarTool, optional but recommended)

1. Power the LD2450 from 5 V only. Open HLKRadarTool within arm's length; its Bluetooth range is very short.
2. Check the firmware version. Update in the app if older than V2.02.23090617 (the version ESPHome requires; a safe floor for any library).
3. Walk toward the doorway and watch your dot. It should track smoothly through the door frame.
4. **Leave the app's area detection / zones OFF.** The firmware does the window logic; zones inside the sensor would silently hide targets from it.

## Fallback: LD2410C

Setting `sensor 2410` switches the trigger back to GPIO33. Its app setup (gates) is in git history of this file; summary: max moving gate 2, max static gate 1, no-one duration 1 s, aim down 45 degrees.

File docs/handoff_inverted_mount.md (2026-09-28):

# Handoff: inverted device on metal corner braces (owner's redesign, 2026-09-27)

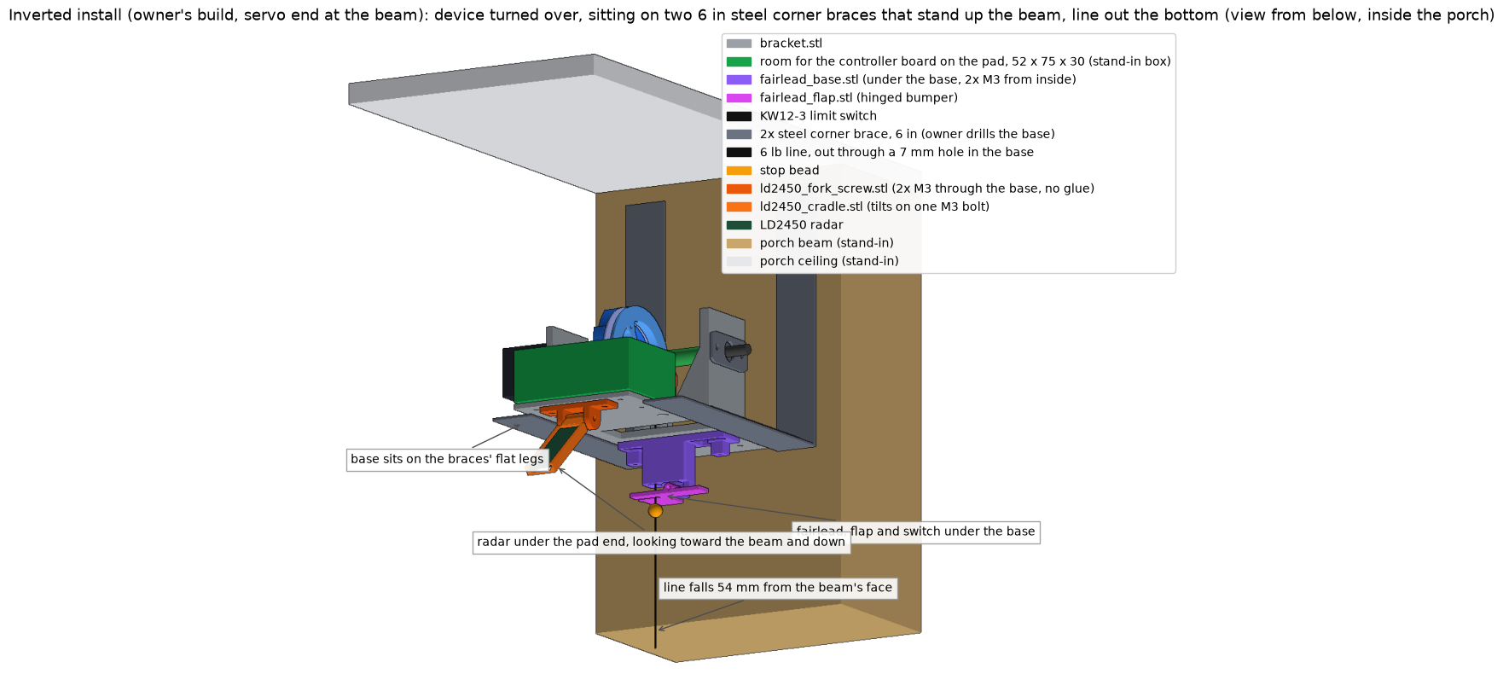
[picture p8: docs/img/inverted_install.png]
Inverted install mockup


## Where it stands: mockup sent, waiting on the owner

Steps 1 and 2 below are done (2026-09-27). `python inverted.py` passes every check: block watertight, mounting face one plane at y 0, no clashes (braces included), line path clear through the base hole, bore and flap slot, spool clearance 0, hard stop 14.75 degrees, roller push 4.33 (needs 3.4), both screw heads clear. Two fixes were needed: the braces became 6 in stand-ins at z 8 and z 106 with no holes, and the fairlead block was trimmed to z 24 to 93 (far rib dropped) to clear them; the face check was rewritten because it wrongly counted the block's own inner steps as mounting faces. `render.inverted_png()` makes the picture above. The full rebuild (`tools\regen_cad.ps1`) was not run: `generate.py` is untouched, and it rewrites every image while another session was live.

Owner's corrections, 2026-09-27, applied the same day and re-checked (all checks above still pass):
- "the mmwave sensor must be attached and part of the device": the ceiling design's fork, cradle and radar are turned over and glued under the base's servo end, looking back toward the beam and down at doc 03's 50 degree tilt. The report now shows 0% of the radar's view blocked by the device, and its centre line passing under the beam's bottom edge (403 below the ceiling against 254). The radar hangs about 30 mm past the base's far end. The hanging spider sits in its view.
- "does that design allow room for the pcb board and esp32": yes. The pad (the base's device side at the beam end, now facing up) is untouched; a 52 x 75 x 30 stand-in box there clears every part.
- Braces "rotated the other way": the flat leg under the base, the other leg standing UP the beam's face beside the device. The base now sits 160 below the ceiling (was 70); the bead rests 179 below it; the beam's bottom edge is 254.

Owner's answers, 2026-09-27: mockup approved; the braces and their holes are his to place and drill by hand; a Fable check of the design after the doc work.

Step 3 done the same day: docs 01 (direction rule 1), 05 (section G), 06 (the wall section is now this install), 08 (V10, V18; the finger item renumbered V20), 09 (`fairlead_base.stl` section), BOM (PRINT-INV, I1, I2; wall lines marked superseded), `cad/README.md`, `README.md`, `fairlead_base` in `generate.py`'s print list, and `cad/bracket_footprint_inverted.svg` (the three drilled holes). Full rebuild run: every check passes and every existing STL and picture came out byte-identical.

Fable cold check the same day (one read-only reviewer, 8 findings, none blocking; all verified and fixed): brace bolt zones added to doc 06 (clear between x 24 and x 55 at either end; never x -20 to 20 at the 606ZZ end, the bearing plate); switch and radar leads routed round the base's far end (docs 05, 06); a boss under the z 28 block screw (it had only the 4 mm plate to bite); line hole 7 mm, wider than the 6 mm barrel channel; the radar fork is now `ld2450_fork_screw.stl`, bolted with 2x M3, no glue (two more holes, x 62, z 45 and z 79); the load line in `inverted.py` rewritten (the braces carry the moment, the base is in compression); the beam clipping the top of the radar's field noted in doc 06; stale numbers below flagged.

The three sections below ("Braces", "What turning it over does", "What has to change") were written before the owner's corrections. Where they disagree with this section or with doc 06 (braces standing down the beam, 1.5 in braces through the pad holes, base 70 below the ceiling, line 113 from the beam, 8 MPa), they are stale.

Still open: nothing is built. The spider sits inside the radar's view (doc 06); the walk test settles whether that matters.

## First job: the mockup, for the owner to check

The owner ruled 2026-09-27: build the inverted layout (yes), he has the corner braces (yes), and he wants an accurate mockup picture first, before any doc work. Do this, in order:

1. `cd cad; python inverted.py`. Fix whatever fails until the report shows: block watertight, mounting face one plane, no CLASH lines, line path clear through base hole, bore and flap slot, spool 2 mm clearance 0, hard stop near 14.75 degrees with roller push at least 3.4, both screw heads clear.
2. Add `inverted_png()` to `cad/render.py`: `assembly_inverted()` plus `porch()`, drawn through `view_inv()` (floor down), a line and bead from `line_and_bead()`, viewed from below inside the porch like `wall_install.png`. Save as `docs/img/inverted_install.png`. Look at it. Put it at the top of this file and send it to the owner. Stop there until he answers.
3. Only after he approves: docs 06 (the wall install becomes this), 09 (block under the base, same flap and switch), 01 (line exits the servo side), 05, 08 (V10 and V18), BOM (braces), `cad/README.md`, and the drilled holes on a second footprint drawing (`footprint_svg.py` sectioning `bracket_inverted()`).

## Braces: 6 in steel L brackets, the owner's ruling 2026-09-27

His words: "i will manually edit the plate via drill or 3d model myself based on the 6inch braces". So the braces are 6 in by 6 in, 1 in wide, about 35 lb rated, and the bracket's bolt holes for them are HIS: he drills the base to the braces' own holes, or edits the model himself. The next session does not place the braces and does not drill holes for them in `bracket_inverted()`.

What the next session still does about them:

- Model the braces as 6 in stand-ins (`BRACE_LEG` 152, `BRACE_W` 25 in `cad/inverted.py`) at whatever z the owner says, and run the clash check against the fairlead block. A 6 in leg reaches from the beam to x +60 under the base; on the pad rows (z 28 and z 83) it runs through the block (x 19 to 36, z 20 to 99), so the braces go at the base's ends (about z 8 and z 106) unless he says otherwise. Ask him which z once, in the mockup message.
- Keep the fairlead block clear of the brace legs: its plate starts at z 24 and its far rib (z 93 to 99) comes off if the braces are at the ends. That is one edit in `fairlead_base()`.
- Leave the drilled holes for the braces out of `bracket_inverted()` and off the footprint drawing. Only the three holes the session owns go in: the line (5 mm at x 25, z 45) and the two block screws (x 32, z 28 and z 83). Any others are his.
- The upright legs stand 152 mm up the beam from the base (owner 2026-09-27: "rotated the other way"), so the base sits about 160 below the ceiling. Capacity is not a question: the device is about 1 lb and the line cannot pull more than 6 lb.

## Ground truth first

This file is a pointer, not a record of truth. The local repo wins. If anything here disagrees with a file, the file is right and this handoff is stale: say so out loud.

```
git log -1 --oneline                                     # where the repo is now
git log -1 --oneline -- docs/handoff_inverted_mount.md   # when this handoff was last true
```

## The owner's words

"all the stress - 'pulling' or tension - is being applied to the 3d print design. Why not invert this entirely - having the tension when line is retracted rapidly from below be inverted by flipping the input/output of string 180 degrees, inverting it so the stress is moreso compaction against the 3d print model - have the string/line exit the 'bottom' of the bracket, the fairlead and all other objects re-oriented 180 degrees so that all the points of potential stress occur from below the bracket and device - not from technically the 'top' of the 3d print model device. This way I can just use some l-shaped metal brackets secured to the very bottom face of the bracket, sidestepping the need to consider PLA 3d print model material weaknesses."
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

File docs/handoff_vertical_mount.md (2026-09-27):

# Handoff: vertical-face mount (draft designed to the owner's plan, print is the next step)

What this is for: the record of the wall install draft for hanging the DropSpider from the inside face of the porch's front beam, and what the next session does once the owner has printed and hung it. The design lives in `cad/wall_hinge.py`; the owner-facing description is the "Alternative: hanging from the beam's inside face" section of `06_installation.md`.

## Ground truth first

This file is a pointer, not a record of truth. The local repo wins. If anything here disagrees with a file, the file is right and this handoff is stale: say so out loud.

Staleness check, run first:

```
git log -1 --oneline                                   # where the repo is now
git log -1 --oneline -- docs/handoff_vertical_mount.md # when this handoff was last true
```

Same hash: nothing landed since it was written. Different: re-verify every state line below against the file it names.

## The owner's ruling, 2026-09-27

His plan, in his words: "retain existing bracket with some modification... hinge on one end (the end containing the pcb mounting plate probably) ---> hinge perpendicular to another plate with opposing hinge for M3 bolt or an additional 6mm axle... then have two eyes at both ends with light duty chain or thin paracord securing both ends of the device + perpendicularly mounted bracket resulting in a 90 degree perpendicular orientation". On being shown a one-piece braced shelf instead: "this is over-engineered dude - that's why MY plan was easy, quick rapid print and working draft". The braced shelf stays in `cad/wall_mount.py` as a fallback and is out of the print list.

## The owner's ruling, 2026-09-27, second pass

On the cord version: "what drawign makes no sense - the hinge plate is excessively short in relation to its utility and where is the 45degree connector between the two plates endsd?" So: the plate is tall, the hinge is at its top, the device sits at the ceiling, and a bar at about 45 degrees joins the far ends of the two plates at each side. That bar is pushed, not pulled (the weight folds the hinge shut), so it is a printed strut, not chain.
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

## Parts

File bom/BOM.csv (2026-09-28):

ref | item | qty | source | asin_or_part | status | notes
M1 | STEPPERONLINE NEMA 11 bipolar 0.67A 6Ncm (round shaft) | 1 | amazon.com | B00PNEPF4O | ordered | Vref 0.85 V
D1 | BIGTREETECH TMC2209 V1.3 stepstick | 1 | amazon.com | B07ZPV4HFP | ordered
D2 | A4988/DRV8825 stepper driver expansion board (2 pk) | 1 | amazon.com | B0FQC39GJ2 | ordered | DIP all OFF
C1 | ESP32 DevKit V1 30-pin CP2102 USB-C (3 pk) | 1 | amazon.com | B0CR5Y2JVD | ordered | either board works; same GPIO numbers
C2 | ESP32-S NodeMCU 38-pin (ESP-WROOM-32 CP2102) | 1 | any |  | have | board in use on the bench (COM13)
S3 | KW12-3 micro switch with roller lever (SPDT) | 1 | any |  | have | in the fairlead (doc 09); COM to GND and NO to GPIO32
H5 | M2 x 12 screws + M2 nuts | 2 | any |  | have? | KW12-3 to the fairlead switch plate
H8 | M2 bolt 16 to 20 mm | 1 | any |  | have | flap hinge pin; threads into the fairlead body
H9 | M3 countersunk (flat-head) screw 8 to 10 mm | 2 | any |  | have? | fairlead body to the pad; heads flush with the ceiling face
H6 | 1.75 mm filament (30 mm piece) | 1 | any |  | have | fairlead flap hinge pin
H7 | M3 bolt 25 to 30 mm + M3 nut (nylon-insert if you have one) | 1 | any |  | have? | radar cradle tilt pivot
S4 | HLK-LD2450 mmWave tracking radar | 1 | any |  | have | PRIMARY trigger (Rev C.1); UART2 GPIO16/17; 4-pin 1.25 mm cable
S1 | HLK-LD2410C mmWave radar | 1 | amazon.com | B0BXDLHHH2 | ordered | fallback trigger on GPIO33
S2 | SG90 micro servo | 1 | amazon.com | B072V529YD | ordered
P1 | 12 V 2 A adapter with screw-terminal jack | 1 | amazon.com | B01AZLA9XQ | ordered
P2 | MP1584EN mini buck module | fixed 5 V out | 5 to 30 V in | 1 | any |  | have | in use; meter 5.0 V before connecting loads
P3 | LM2596 buck converter (5 pk) | 1 | amazon.com | B0D4HQ48H3 | ordered | spare; replaced by the MP1584EN
H1 | uxcell 5 to 6 mm rigid coupler L20 D12 | 1 | amazon.com | B07P5Z25H8 | ordered | blue threadlocker
H2 | 6 mm x 100 mm hardened chrome rod | 1 | amazon.com | B0D2BK3X8P | ordered
H3 | HF0612 one-way needle bearing | 1 | amazon.com | B0BKY2ZSTR | ordered | 5 pk; orientation matters
H4 | 606ZZ bearing 6x17x6 | 1 | amazon.com | B0FQ4WJ8FQ | ordered | 10 pk
N1 | 2 mm round elastic cord | 150 mm | any |  | ONLY IF | snubber: only if the line is braid or fluorocarbon; not with 6 lb mono
N2 | 8 mm hard plastic bead | 1 | any |  | TO BUY | stop bead
N3 | small fishing barrel swivel (size 10 to 14) | 1 | any |  | TO BUY
N4 | 6 lb nylon monofilament fishing line | 2 m | any |  | have? | its stretch is the shock absorber; snaps at about 27 N
N5 | 470 uF 16 V electrolytic capacitor | 1 | any |  | ONLY IF ESP32 RESETS | at the servo; skip unless the board restarts when the finger moves
N6 | 5.5 x 2.1 mm DC extension cable 3 to 5 m | 1 | any |  | TO BUY | 12 V to ceiling
N7 | #4 x 1 in pan-head screws + ribbed drywall anchors | 4 | any |  | TO BUY | ceiling install only; the inverted install screws the owner's braces to the beam with his own screws
N8 | M3x8 self-tapping or machine screws | 3 | any |  | have? | spool disk to body
N9 | M2.5x6 screws | 4 | any |  | have? | motor
N10 | 4-conductor cable 1 m or dupont extensions | 1 | any |  | have? | sensor lead
N11 | soft foam spider <=60 g | 1 | any |  | TO BUY | Rev C.1: motor must stop it
N12 | 74AHCT125 quad buffer | 1 | any |  | ONLY IF V1 FAILS | logic level
PRINT | bracket / spool_body / spool_ratchet / fairlead_body / fairlead_flap (+1 spare) / finger (+1 spare) / ld2450_fork_screw / ld2450_cradle / spacer_A_6mm / spacer_B_50mm / shims only if needed |  | printed | cad/stl |  | PLA; finger PETG preferred; cad/retired/line_guide.stl is obsolete
PRINT-INV | fairlead_base (replaces fairlead_body) | 1 | printed | cad/stl | ONLY IF inverted install | doc 06 alternative and doc 09
I1 | M3 x 12 screw | 2 | any |  | have? | inverted install only: fairlead_base to the base from inside; cuts its own thread
I3 | M3 x 10 bolt + M3 nut | 2 | any |  | have? | inverted install only: ld2450_fork_screw to the base | nuts inside
H10 | M3 x 10 countersunk screw + M3 nut | 2 | any |  | have? | ceiling install: ld2450_fork_screw to the base | heads flush with the ceiling face | nuts on the fork
I2 | steel corner brace 6 in + screws for the beam and bolts for the base | 2 | any |  | owner has | inverted install only: the owner places and drills them

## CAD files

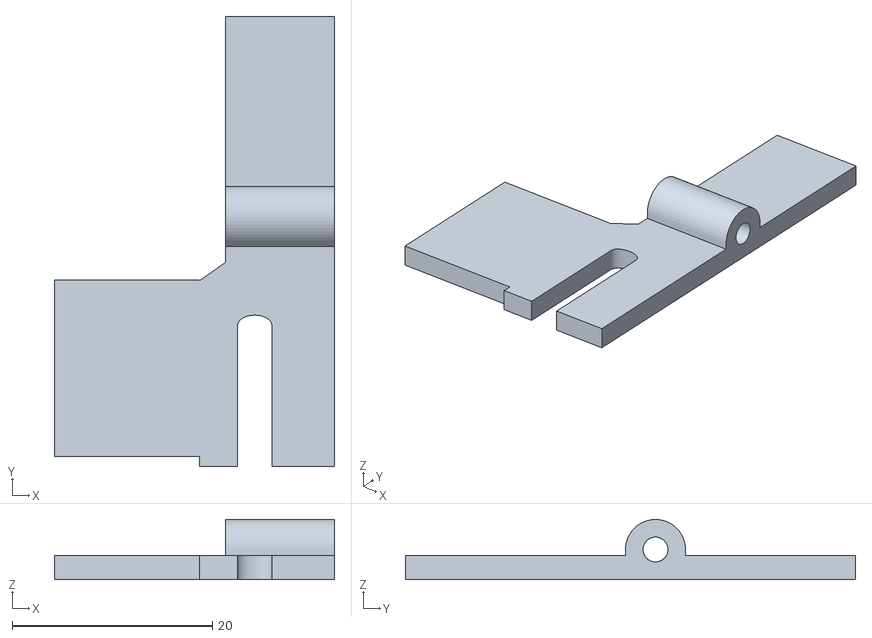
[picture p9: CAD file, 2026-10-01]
cad/stl/fairlead_flap_inv.stl
28.0 x 45.0 x 6.00

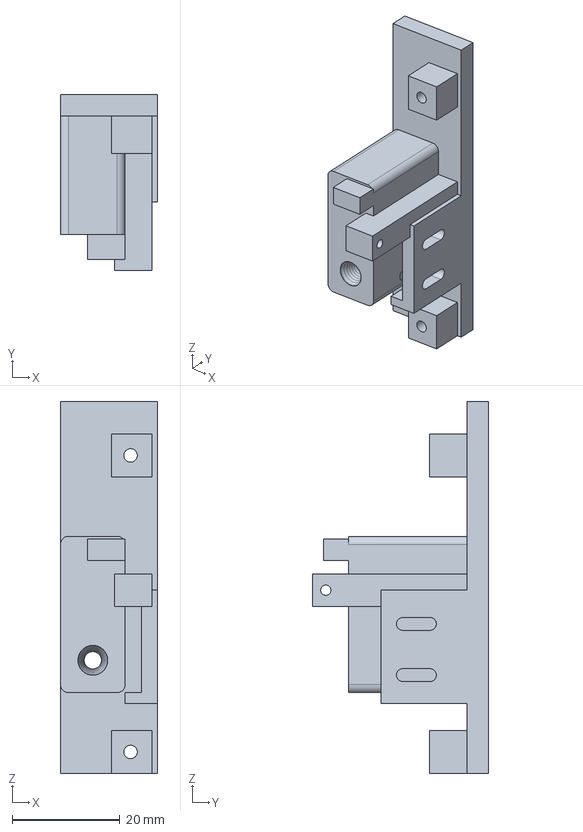
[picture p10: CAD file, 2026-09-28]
cad/trial_build123d/fairlead_base_b3d_rounded.step
18.0 x 32.7 x 69.0 mm

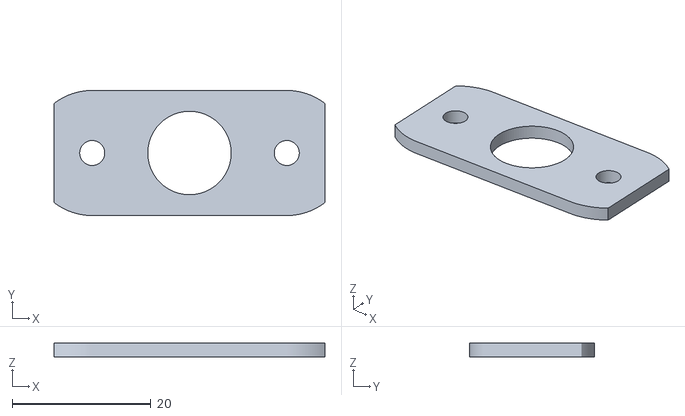
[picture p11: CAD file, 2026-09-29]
cad/stl/bearing_retainer.stl
39.0 x 18.0 x 2.00

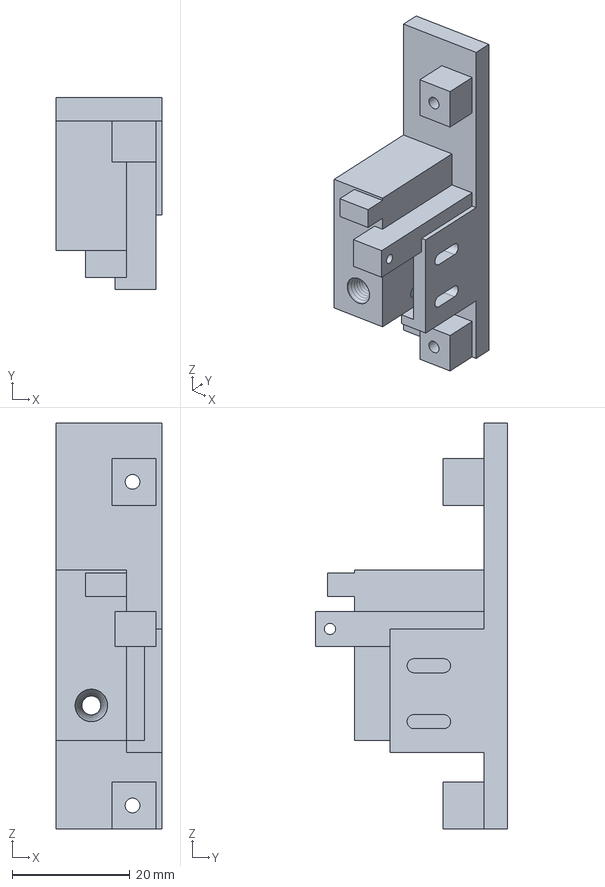
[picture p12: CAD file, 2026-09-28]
cad/trial_build123d/fairlead_base_b3d.step
18.0 x 32.7 x 69.0 mm

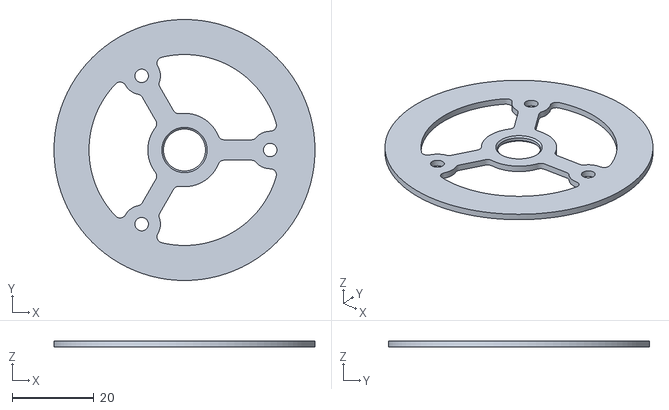
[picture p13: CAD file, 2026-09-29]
cad/stl/spool_shield.stl
64.0 x 64.0 x 1.50

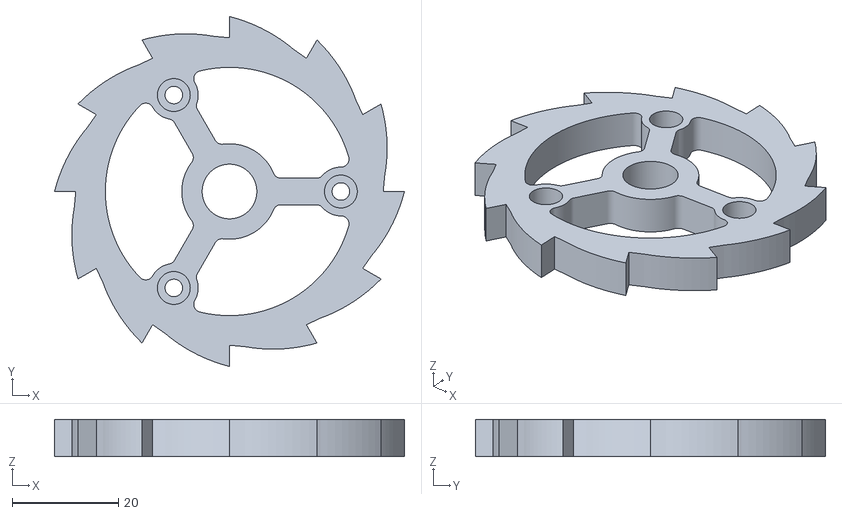
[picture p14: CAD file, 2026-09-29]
cad/stl/spool_ratchet.stl
66.0 x 66.0 x 7.00

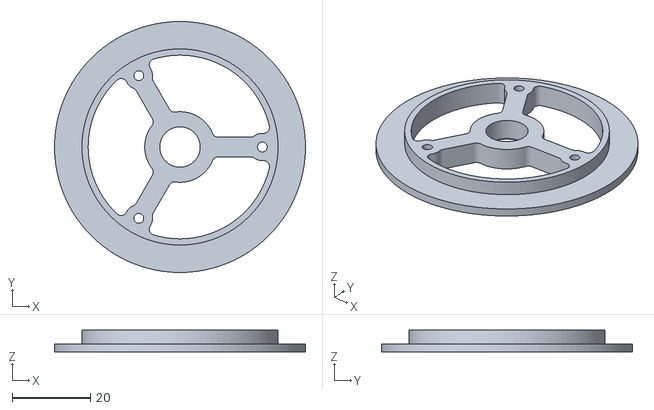
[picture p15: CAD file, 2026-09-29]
cad/stl/spool_body.stl
64.0 x 64.0 x 5.50

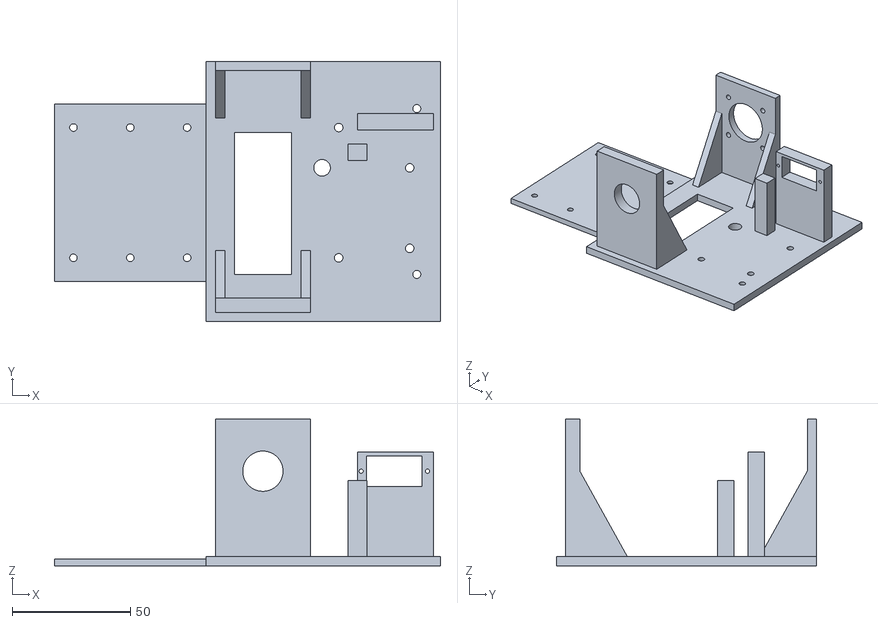
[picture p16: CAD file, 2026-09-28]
cad/stl/bracket.stl
163.0 x 110.0 x 62.0

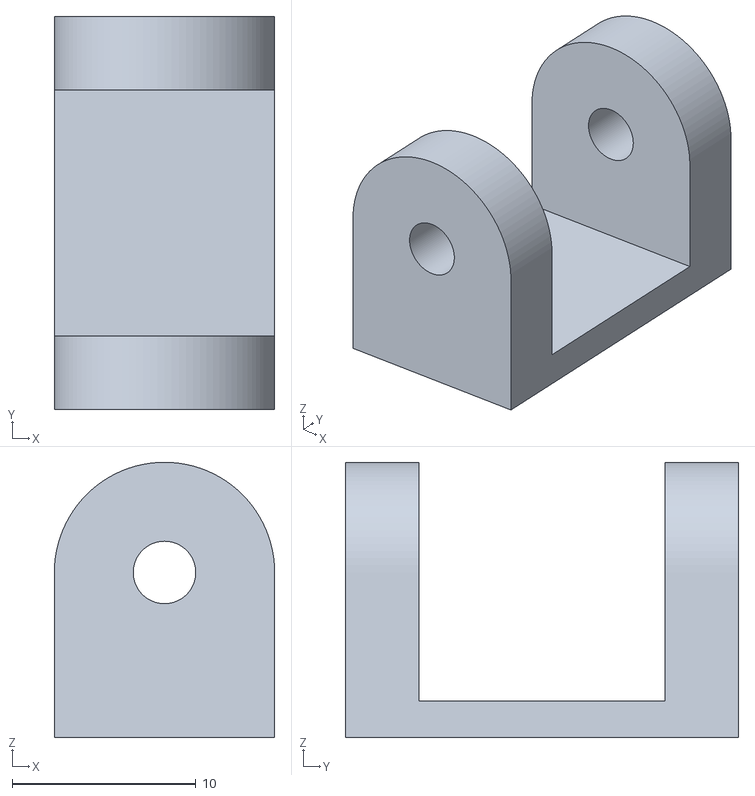
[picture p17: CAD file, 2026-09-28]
cad/stl/ld2450_fork.stl
12.0 x 21.4 x 15.0

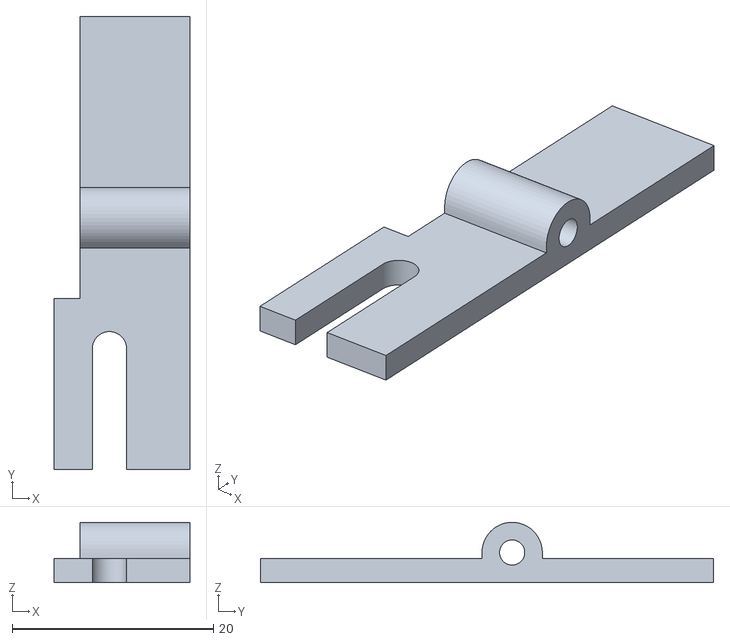
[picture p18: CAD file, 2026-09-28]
cad/stl/fairlead_flap.stl
13.5 x 45.0 x 6.00

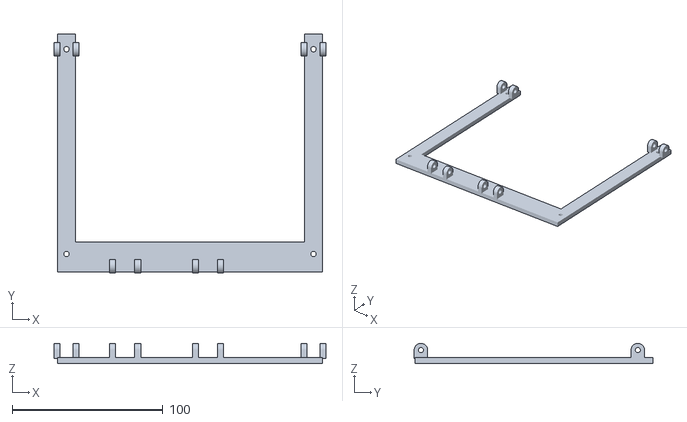
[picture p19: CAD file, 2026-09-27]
cad/stl/hinge_plate.stl
180.6 x 158.5 x 13.5

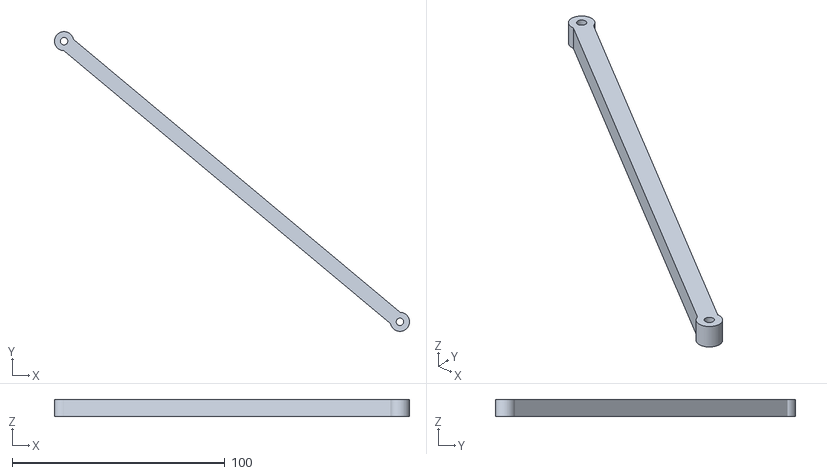
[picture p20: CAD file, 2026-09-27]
cad/stl/strut.stl
167.0 x 141.0 x 8.00

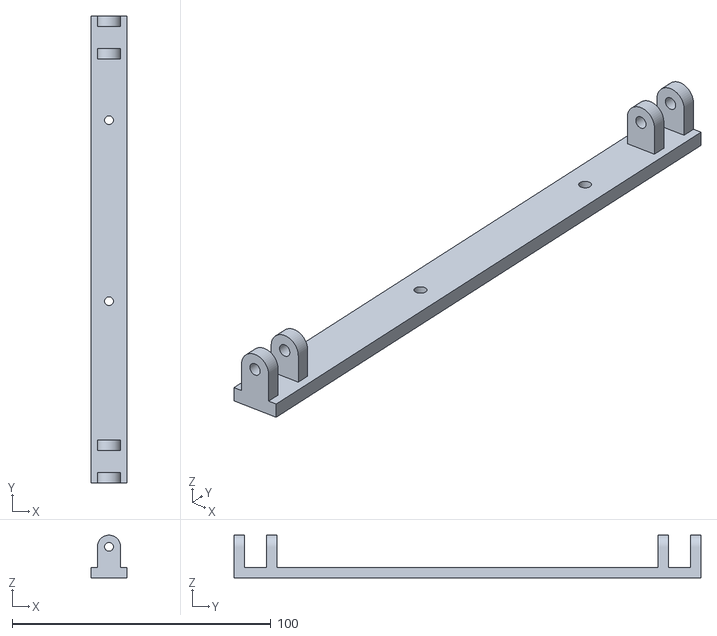
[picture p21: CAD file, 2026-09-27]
cad/stl/tie_bar.stl
14.0 x 180.6 x 16.5

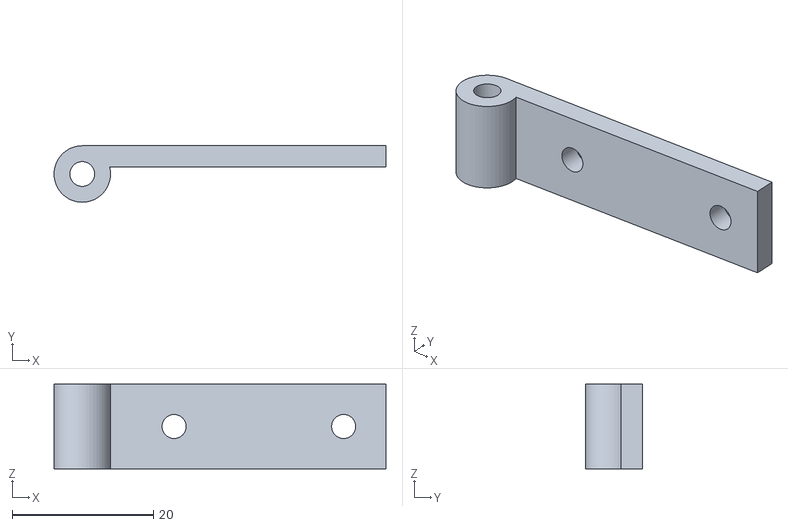
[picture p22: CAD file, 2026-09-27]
cad/stl/hinge_clip.stl
47.0 x 8.00 x 12.0

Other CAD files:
cad/stl/fairlead_base.stl
cad/stl/fairlead_body.stl
cad/stl/finger.stl
cad/stl/spacer_B_50mm.stl
cad/retired/line_guide.stl
cad/stl/DropSpider-inline.3mf
cad/stl/ld2450_cradle.stl
cad/stl/ld2450_fork_screw.stl
cad/stl/line_guide.stl
cad/stl/shim_1mm.stl
cad/stl/shim_2mm.stl
cad/stl/spacer_A_6mm.stl

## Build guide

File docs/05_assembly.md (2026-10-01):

# 05 - Print and assembly

Time: about 5 h printing, 1 h assembly. Tools: small Phillips, 1.5 mm and 2 mm hex keys (coupler set screws), multimeter, vise or bar clamp, CA glue, blue threadlocker, hair dryer.

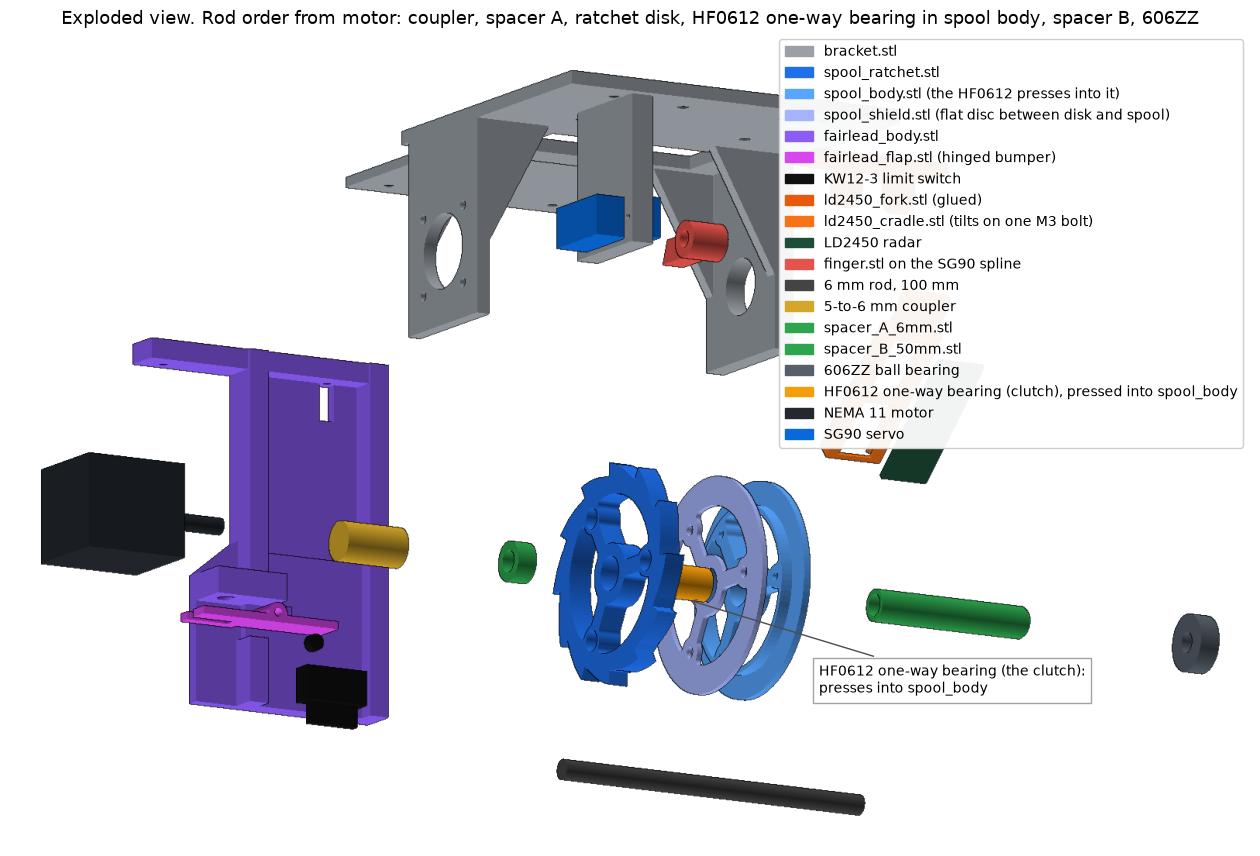
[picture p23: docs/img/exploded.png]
Exploded


## A. Print

All PLA except the finger (PETG if you have it). Settings table in `01_mechanical_design.md`. Minimum set: 1 of each part. Spares worth printing: 1 extra finger, 1 extra flap. Shims only if step 8 calls for them.

## B. Sub-assemble the spool

1. Stack before the bearing goes in: `spool_shield` (the flat 64 mm disc, either face) on the flat face of `spool_body`, then `spool_ratchet`, its flat face (no counterbores) on the shield. Line up the three screw holes and drive **3x M3x8** into the body. Snug, do not strip. The three must sit flat on each other with no gap at the rim. Then press the **HF0612** in from the flange side, through all three 10.3 mm holes, until it is flush with the flange.
2. Check its direction now: push a spare piece of the 6 mm rod in, hold the rod, and spin the body. It must spin freely one way and lock the other. Mark the free direction on the flange with a marker.
3. Check the stack again: no gap at the rim anywhere round. If there is one, back the screws off, scrape any lip off the hole edges, and tighten again.
4. Look at the spool from the **ratchet disk side** (this side faces the motor, so this is the view from behind the motor). The free direction marked in step 2 must be **clockwise** from this side, so it locks counterclockwise (Rev C.1; Rev C had this backwards). If not, press the bearing out and flip it.
5. Fix the **6 lb monofilament** to the barrel, between the flanges. Anchor it with a toggle, not glue alone: drill a **1 mm hole** straight through the barrel's skin (it is 1.6 mm thick) into one of the spoke windows, in the middle of the barrel's width and midway between two spokes. Push the line in from outside, fish it out of the window's open end at the flange face, tie it round a 10 mm stub of 1.75 mm filament (a double overhand), and pull it back so the stub lies across the hole inside the window. A drop of CA on the knot. The stub cannot pull through a 1 mm hole, so the line cannot slip round the barrel even if the spider runs the line out. Then wind clockwise (seen from behind the motor), the first turn over the line's tail. No elastic, no braid. (An arbor knot with CA, the angler's reel knot, also works, but it can turn on the smooth printed barrel once the line is all out.)

## C. Frame and rod

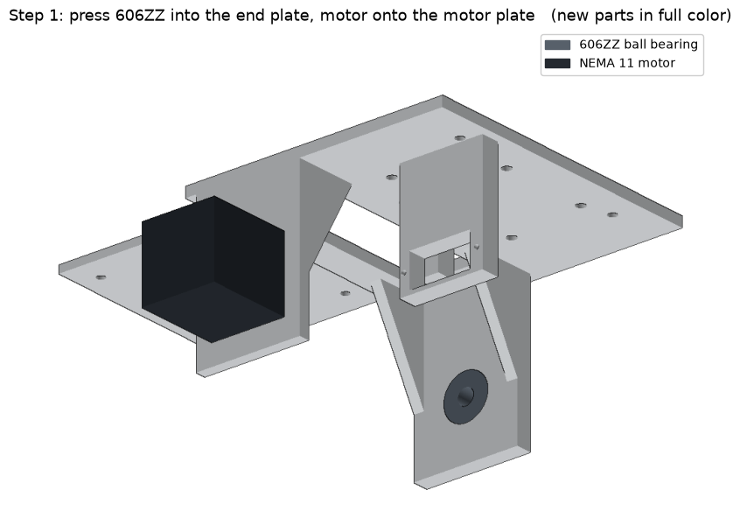
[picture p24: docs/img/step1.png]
Step 1


6. Press the **606ZZ** into the end plate. If it goes in loose (a seat softened by heating the bearing, or an older bracket), fit `bearing_retainer` on the end plate's outside face: drill two 2.5 mm pilots through the end plate using the retainer's holes as the guide, then 2x M3 x 6 to 8. The rod passes through its 12 mm hole and sticks out past it by about 14 to 17 mm; that is expected. Screw the **NEMA 11** to the outside of the motor plate, 4x M2.5x6, wires pointing toward the base.

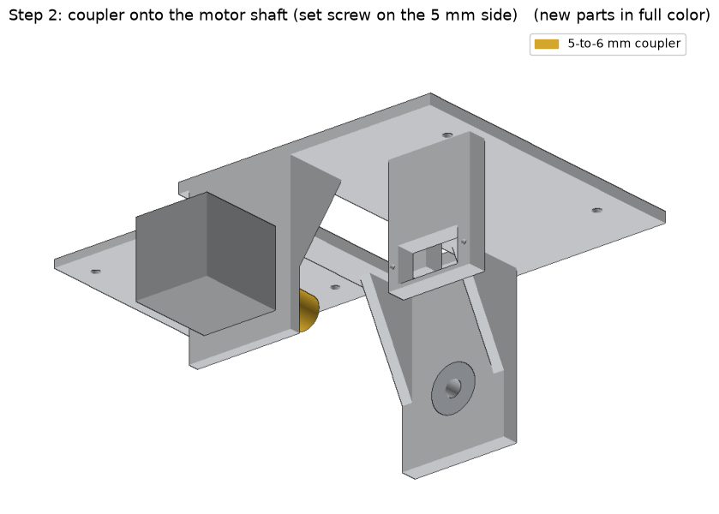
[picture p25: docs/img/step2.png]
Step 2


7. Slide the **coupler** onto the motor shaft, 5 mm side, until the shaft stops. Blue threadlocker, tighten that set screw. Leave the 6 mm side loose.

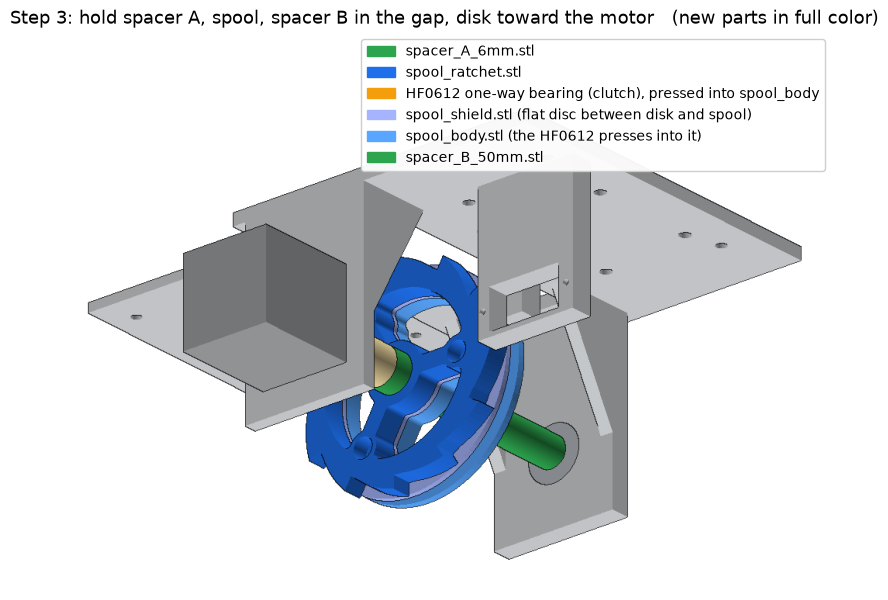
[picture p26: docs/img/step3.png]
Step 3


8. Measure from the motor plate's outer face to the free end of the coupler. **30 mm:** use `spacer_A_6mm`. **26 mm:** use the old 10 mm spacer A if you have one. **27 to 29 mm:** `spacer_A_6mm` plus `shim_1mm` / `shim_2mm` to make up the difference. **Over 30:** sand spacer A down by the difference.
9. Hold, in line inside the frame: spacer A (next to the coupler), the spool (ratchet disk toward the motor), spacer B. **Owner's build (2026-09-29):** snug but not tight took about **4 mm of shim on the motor side of the spool** and **5 mm on the 606ZZ side**. Stack to fit your own frame the same way, then check the ratchet disk still sits between the finger's faces.

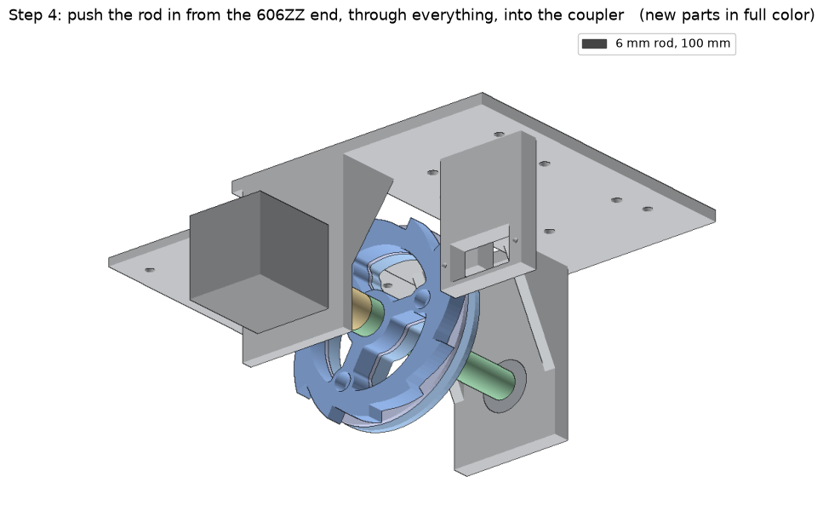
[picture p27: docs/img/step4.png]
Step 4


10. Push the **6 mm rod** in from the outside of the 606ZZ plate: through the bearing, spacer B, spool (rotate the spool its free way as the rod enters the needles), spacer A, into the coupler until it bottoms. Blue threadlocker, tighten the 6 mm set screw.
11. Check: the spool spins freely by hand clockwise (seen from behind the motor), and turning it counterclockwise drags the motor shaft round with it. The stack is snug with no end play above 0.5 mm.

## D. Servo and finger

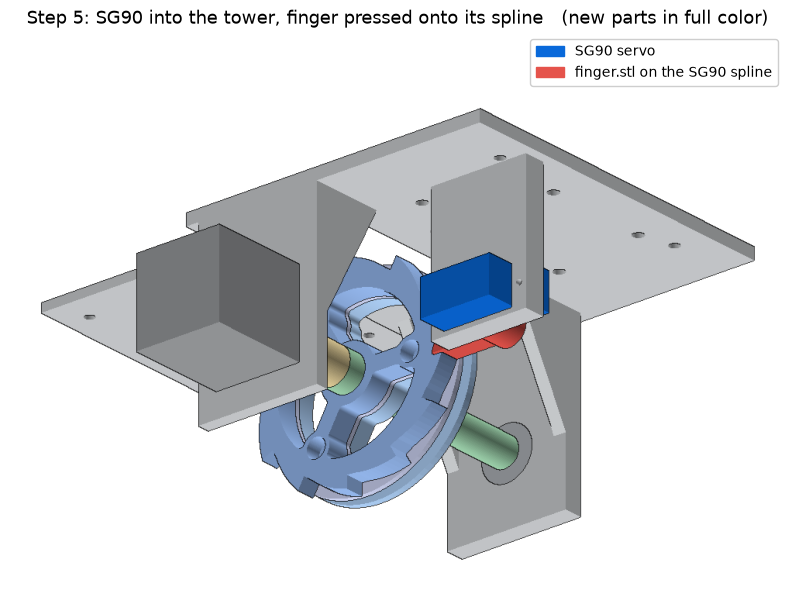
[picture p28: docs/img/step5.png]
Step 5


12. Drop the **SG90** into the tower pocket from the 606ZZ side, output spline toward the spool, wires out the far end. Two tab screws.
13. Power the servo (or do this at commissioning): send it to 90 degrees. No horn is used.
14. Press the **finger's hub** straight onto the servo spline, pointing at the rod, level, resting just above the ledge, tip in the teeth. The socket is round, so it goes on at any angle. Push until the spline bottoms in the socket, then drive the horn screw in from the top, down the 7.4 mm recess. If it is loose on the spline, a drop of CA in the socket; if too tight to push on, turn a 5 mm drill through the socket by hand. Check edge-on: the 7 mm finger covers the 6 mm ratchet disk; at least 5 mm must overlap. If not, move the disk with spacer A and the shims (step 8).

Lock detail

## E. Fairlead, limit switch and line

One `fairlead_body` and one `fairlead_flap` per build. Full detail in `09_fairlead_switch.md`.

Fairlead sub-assembly

15a. Clear the fairlead bore with a 3 mm drill turned by hand. A scrap of the line must slide through without catching.
15b. KW12-3 switch onto the switch plate: roller end toward the fairlead, body on the side away from the flat back. 2x M2 x 12 through the slots, nuts on the switch side, finger-tight.
15c. Flap knuckle into the gap under the fairlead. Hinge pin: an **M2 bolt, 16 to 20 mm**, in from the flap's outer side: free through the flap (open the flap's hole with a 2.5 mm drill by hand if it drags), then it cuts its own thread into the body's hole. Stop before the head clamps the flap. Check the flap swings down under its own weight.
15d. Flap level on its rest stop: slide the switch up until the roller just touches the flap's tail, back off a paper's thickness, tighten. Lift the flap's free end by hand: click at about 2 mm, then it stops flat against the fairlead.

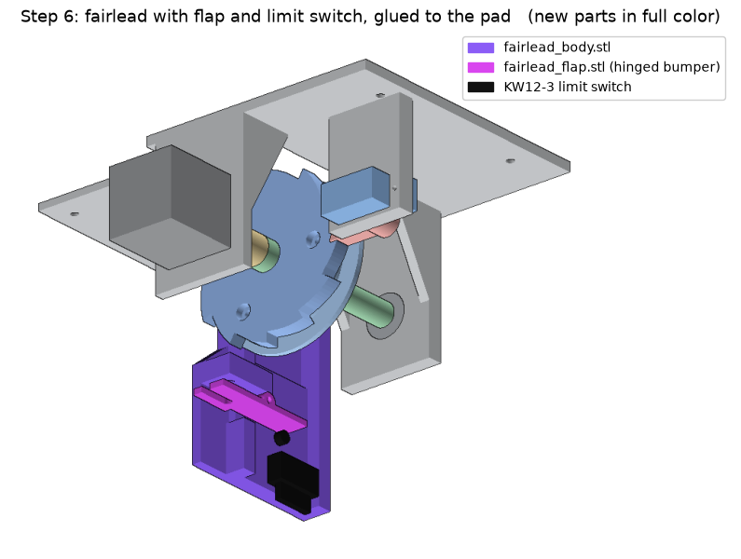
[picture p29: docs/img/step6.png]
Step 6


15. Screw `fairlead_body` to the pad: 2x **M3 countersunk (flat-head) screws, 8 to 10 mm**, put in from the ceiling side down through the x = -32 pad holes, heads flush with the ceiling face, cutting their own thread into the fairlead's rail (2.5 mm pilots). No glue (owner 2026-09-26). The pad holes need a 90 degree countersink so the heads sit flush: new bracket prints have it; on an already printed bracket, twist an 8 mm drill bit by hand in each of the two holes from the ceiling side until a screw head sits flush or just below.
16. Wind the line onto the spool by turning it clockwise (seen from behind the motor). The free end leaves the spool on the pad side; thread it down through the fairlead, then slide it into the flap's slot from the flap's free end.
17. Below the flap, in order: **8 mm bead** (slides on the line; this is what lifts the flap), **barrel swivel** (tie the line to it with an improved clinch or palomar knot; the bead rests on it), **spider** tied to the swivel's other end.
18. Unwind fully and measure from the barrel knot to the bead, line straight but not pulled. That is the `line` value for the firmware.

Spider home

## F. Electronics

19. Meter the 5 V buck (MP1584EN, fixed, not adjustable): 4.95 to 5.05 V before connecting any loads.
20. Set the TMC2209 Vref to 0.85 V, motor unplugged. DIP switches all OFF.
21. Wire per `02_electrical.md` (LD2450 on GPIO16/17, KW12-3 NO to GPIO32 and COM to GND). Mount the controller board on the pad with foam tape or zip ties through the x = -80 holes. Keep the x = -56 holes and the two at the servo end clear: they are the ceiling screw holes.
22. Go to `07_commissioning.md` before mounting anything overhead.

## G. Inverted install only (device turned over on the beam's face, doc 06)

23. Bracket printed from 2026-09-28 on: the five holes are already there, skip to 24. Older print: drill the base: 7 mm at x 25, z 45 (the line; a 1/4 in bit is close enough), 3.4 mm at x 32, z 28 and z 83 (the fairlead block), and, on every print, 3.4 mm at x -80, z 38.5 and z 72.5 (the radar fork at the pad end; the owner's build has the servo end at the beam, 2026-10-01). Print `cad/bracket_footprint_inverted.svg` at 100% as a template. Sand the 7 mm hole smooth. The brace bolt holes are the owner's; doc 06 says where they can go.
24. Print `fairlead_base.stl` instead of `fairlead_body.stl`. Fit the flap and switch to it as in steps 15a to 15d, then screw it under the base with 2x M3 x 12 from inside the base.
25. Bolt `ld2450_fork_screw.stl` under the base at the pad end, on the x -80 holes, plate against the base, ears hanging down: 2x M3 x 10 up through the fork and the base, nuts inside. No glue. Cradle on one M3 bolt through the fork's ears, radar slid into the cradle (doc 03), looking along the device toward the beam (the servo end) and down, 50 degrees to start. The nuts sit inside under the board's edge: keep that strip clear or lift the board on 4 mm foam tape.
26. Wind the line clockwise (seen from behind the motor) as in step 16, but lead it off the spool's **servo side**, down through the base hole, the block's bore and the flap's slot.
27. Leads: the switch and radar leads go round the base's pad end and back to the board (about 15 and 10 cm), tied to the base clear of the spool.
28. The braces and their holes are the owner's. Then `07_commissioning.md` as usual.

## Base layout reference

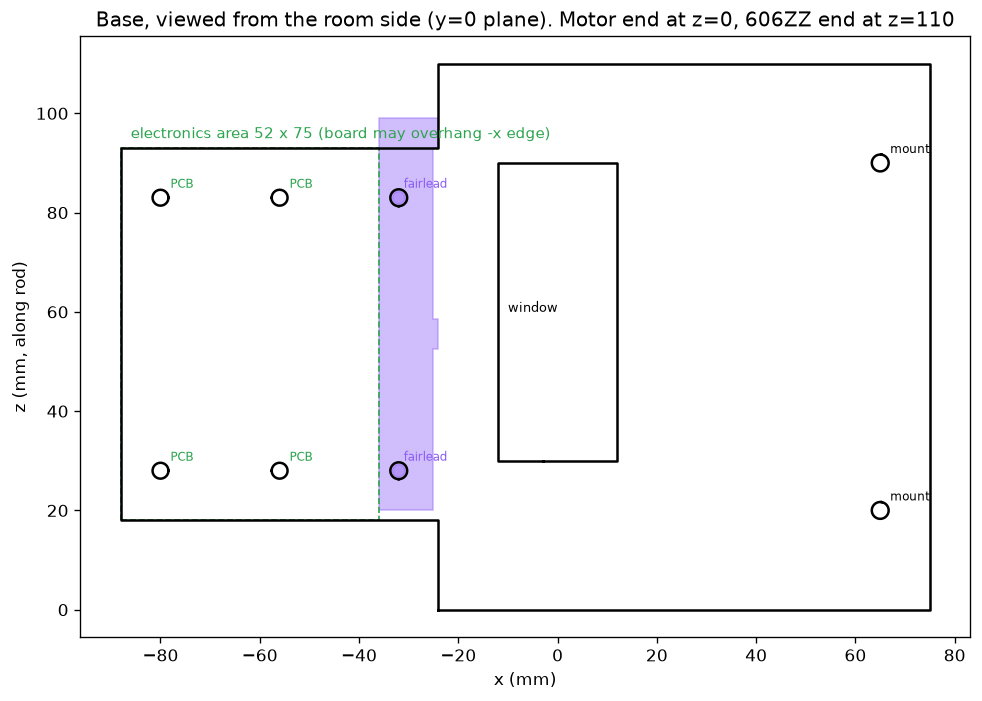
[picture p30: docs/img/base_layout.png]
Base


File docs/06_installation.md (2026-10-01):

# 06 - Installation under the porch

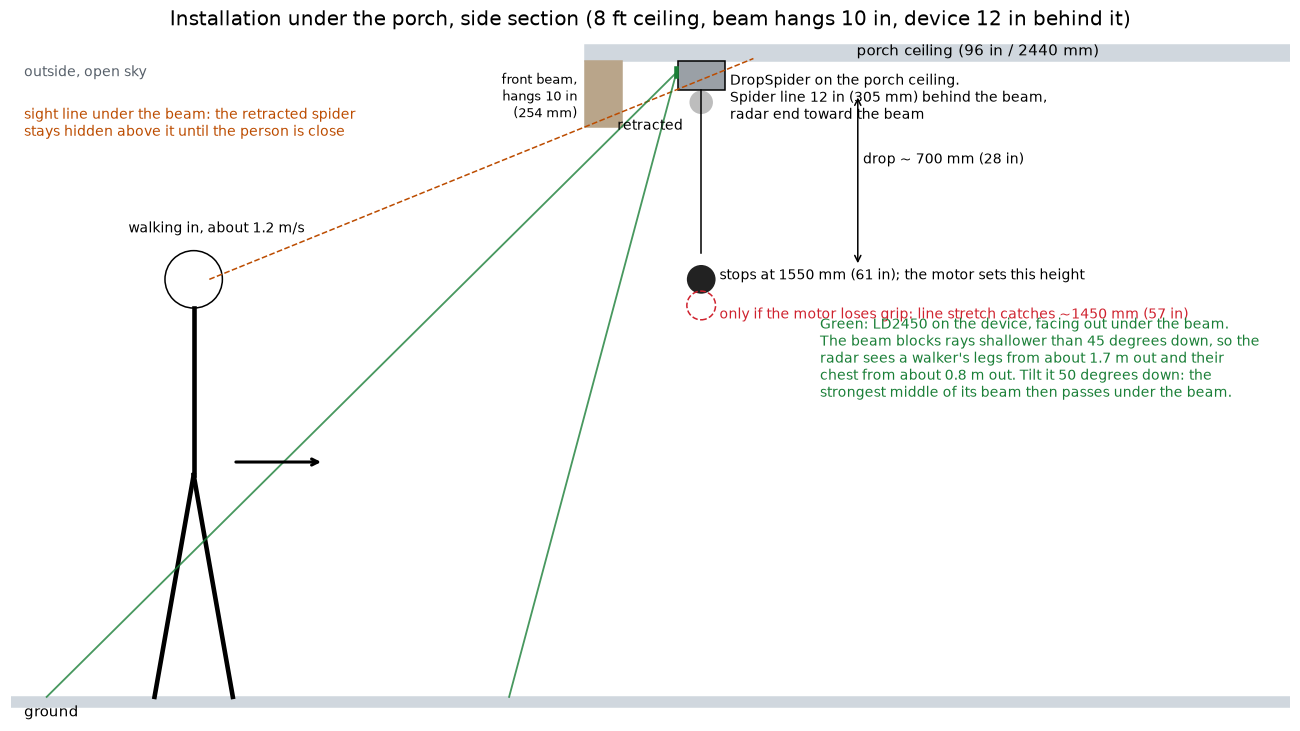
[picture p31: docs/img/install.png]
Install


## Where it goes

Porch measured by the owner 2026-09-26: ceiling 8 ft, front beam hangs 10 in below it, device 12 in behind the beam.

- **On the porch ceiling, behind the front beam.** People walk in from outside, under the beam.
- Spider line (the fairlead) **305 mm (12 in) behind the beam's back face**, centred on the walkway.
- Rod axis parallel to the beam. **Servo end, with the radar, toward the beam**; the fairlead end away from it.
- The device hangs about 112 mm below the ceiling at its lowest point (the limit switch). Retracted, the spider's bottom sits about 215 mm below the ceiling, above the beam's bottom edge (254 mm below the ceiling), so the beam hides it until the person is close.
- **Radar tilt 50 degrees down** for this porch. The beam blocks every radar ray shallower than about 45 degrees down; at 50 the middle of the radar's beam passes under it. Worked out from the measurements (drawn in the picture): legs visible from about 1.7 m outside the beam, chest from about 0.8 m. Not yet walk-tested (test S3). Radar partly sees through wood too; the walk test settles it. **Not through metal.** The radar sees through wood, drywall and plastic, but aluminum siding or trim coil blocks it completely, however thin (at 24 GHz the signal dies within about half a micron of aluminum; Hi-Link's manual and every install guide say metal blocks it). If the beam is clad in aluminum, the radar only sees people once they are in view under the beam's bottom edge, and the flat metal can bounce the signal back as phantom targets or jumpy positions. Fix for either: tilt steeper, so less of the view lands on the beam.

## Heights (8 ft porch ceiling, beam 10 in deep)

| Point | Height |
|---|---|
| Porch ceiling | 2440 mm (96 in) |
| Bottom of the front beam | 2184 mm (86 in) |
| Spider, retracted | bottom of spider about 2230 mm, hidden above the beam's bottom edge |
| Spider at rest after the drop | 1550 mm (61 in): face height for teens and adults, above small children |
| Lowest point if the motor loses grip and the line's stretch catches it | about 1450 mm (57 in) |

Line length to set (barrel knot to bead) = (ceiling - 85 mm) - (target rest height + spider height + 30 mm for bead and swivel) + 45 mm.
The 85 mm is where the bead sits against the flap at home; the 45 mm is line between the spool and the flap.
For the table above with a 100 mm spider: 2355 - 1680 + 45 = 720 mm. Tie it at 720, enter `line 720`, then shorten on site until the resting height is right.

## Fastening

- 4 screws: the 2 holes at the servo end and the 2 pad holes at x = -56 (the middle pair).
- Into a joist: #4 x 1 in pan-head wood screws.
- Into drywall only: #4 screws in ribbed plastic anchors, or small toggle anchors. With 6 lb mono the peak pull is about 12 N (1.2 kg) and can never pass about 27 N, where the line snaps. Never hang it on braid without an elastic snubber.
- The ceiling face must be flat against the base; nothing may stick out of the ceiling side (this is why the fairlead's two screws are countersunk flush).

## Alternative: turned over on the beam's inside face (inverted install)

Inverted install

The owner's plan, approved 2026-09-27: the device turned upside down, its flat base at the bottom, sitting on two steel corner braces screwed to the beam's inside face. The line leaves through a hole in the base. Every load (the device's weight, the line's pull) presses the printed parts down into the base and the base onto steel, instead of hanging the PLA from screws. CAD-checked, **not yet built or hung** (open item V18). Source `cad/inverted.py`; run it for the report.

**Turned end for end in the owner's build (photo 2026-10-01):** the **servo end** of the base sits at the beam, the pad (electronics) end away from it. The radar moves to the pad end so it still looks toward the beam. Everything below is for that build.

**What changes on the device.** Nothing in the mechanism or the firmware: same spool, clutch, ratchet, finger, servo, same winding sense, same `dir`. The line simply leaves the barrel on the servo side instead of the pad side (doc 01, direction rule 1).

| Part | What happens to it |
|---|---|
| Bracket | `bracket.stl` from 2026-09-28 has these five holes printed in (with the 17.0 606ZZ seat). On an older print, drill them through the base (drawing `cad/bracket_footprint_inverted.svg`, print it 1:1 as a template): **7 mm for the line** at x 25, z 45 (wider than the spool's 6 mm line channel, so the line never rubs a drilled edge; a 1/4 in bit is close enough); **3.4 mm x2 for the fairlead block** at x 32, z 28 and z 83; **3.4 mm x2 for the radar fork** at x -80, z 38.5 and z 72.5 (the pad end; drill these on every print, the printed holes at x 62 stay empty) |
| `fairlead_base.stl` (new, 18 cm3) | The fairlead, hard stop, rest stop and switch plate of doc 09 as one block under the base, at the line hole. Same flap (`fairlead_flap.stl`), same KW12-3, same hinge bolt. 2x M3 x 12 from inside the base (heads on the device side) into the block's 2.5 mm pilots. Replaces `fairlead_body.stl` for this install |
| Radar | Stays on the device, no glue: `ld2450_fork_screw.stl` (the fork with a longer plate and two holes; same ears, so the same cradle and radar) bolted under the base at the pad end with 2x M3 x 10, nuts inside, looking along the device toward the beam (where people come from) and down at 50 degrees. The nuts sit 8 mm from the base's end, under the board's edge: keep that strip clear or lift the board on 4 mm foam tape |
| Controller board | On the pad, the base's device side, now the end away from the beam, facing up. Room checked: a 52 x 75 x 30 mm box there clears every part |
| Braces | **The owner's:** two steel corner braces, 6 in legs. The flat leg under the base, the other leg standing up the beam's face beside the device's servo end. He places them and drills the base for their bolts himself. **Where a bolt can go**, checked in the model: the base only runs full width between x -24 and x 75, so at its two ends (z 0 to 18 and z 93 to 110) there is no pad and the flat legs carry the base from the servo end (x 75) to x -24; past that they run on under nothing to their tips at x -73. A bolt through the base is clear of everything inside between **x 24 and x 55** at either end, and at the motor end also between x -12 and x 12. Never between x -20 and x 20 at the 606ZZ end: the bearing plate stands there. The pad's own holes at x -80 and x -56 are not over the braces. Drawn in the model at z 8 and z 106, clear of the fairlead block; nearer the middle they hit it |

**Heights**, from the model, with 6 in braces standing up the beam with their tops about 8 mm under the ceiling:

| Point | Below the ceiling |
|---|---|
| Base (the device's bottom face) | 160 mm |
| Bead at home, against the flap | about 196 mm (fairlead v2, 2026-09-28; v1 179) |
| Spider retracted, bottom | 196 + 30 (bead and swivel) + spider height. Hidden behind the 254 mm beam only for a spider up to about 28 mm tall |
| Line | falls 54 mm from the beam's face (ceiling install: 305 mm). A spider wider than about 10 cm brushes the beam; the owner's is about 8 cm, so about 14 mm to spare while it hangs still (owner kept this layout 2026-10-01) |

Line length (barrel knot to bead) = (ceiling - 196) - (target rest height + spider height + 30) + 72. The 72 mm is line from the spool to the flap in this layout (fairlead v2, doc 09). Tie it, enter `line`, then shorten on site, as for the ceiling install.

**Radar view**, from the model: the device blocks none of the radar's field (60 degrees either side, 35 up and down); its centre line meets the beam's face plane 409 mm below the ceiling, under the beam's bottom edge (254). The beam does cut off the top of the field: anything shallower than about 19 degrees below level hits the beam, as in the ceiling install (doc 03). **Not through metal.** The radar sees through wood, drywall and plastic, but aluminum siding or trim coil blocks it completely, however thin (at 24 GHz the signal dies within about half a micron of aluminum; Hi-Link's manual and every install guide say metal blocks it). If the beam is clad in aluminum, the radar only sees people once they are in view under the beam's bottom edge, and the flat metal can bounce the signal back as phantom targets or jumpy positions. Fix for either: tilt steeper, so less of the view lands on the beam. Start the walk test at 50 degrees; if it fires late or fires on nothing, go to 55 or 60. The cradle clears every part from 20 to 90 degrees in this layout (checked in the model 2026-10-01). The radar hangs about 35 mm past the base's pad end. The spider, retracted or dropped, is inside its view: if the radar reports the spider as a person, the device would sit in "waiting for the doorway to clear" after each scare. Not checked; the first walk test (S3) shows it, and a steeper or shallower tilt moves the spider out of the middle of the view.

**Wires.** The switch and the radar now sit under the base and the board on top of it. Run both leads round the base's pad end (the servo end is against the beam) and back to the board: about 15 cm for the switch, about 10 cm for the radar (BOM N10 covers it). Tie them to the base so the spinning spool cannot catch them.

**Order.** Bench: drill the five holes, screw the fairlead block on (doc 09, inverted install), bolt the radar fork under the pad end, board on the pad, leads round the pad end, line threaded down through the base hole. Ladder: braces to the beam, device onto their flat legs, bolted through the owner's holes. Then `07_commissioning.md` as usual.

Retired 2026-09-28: the earlier hinge-and-strut wall draft and the braced shelf. Their code and STLs are in `cad/retired/`, their handoff and picture in `docs/retired/`. Do not print them.

## Sensor

- Outdoors under a covered porch: keep the device and controller out of blowing rain; the LD2450 and the electronics are not waterproof.

- **LD2450** (primary): on the device, in its tilting cradle under the servo end (`ld2450_fork_screw.stl` bolted with 2x M3, no glue; `ld2450_cradle.stl` on one M3 bolt), looking out from under the porch toward people walking in, standing upright. Set the tilt on site, starting at 20 degrees down (doc 03). Nothing to mount on the wall. Inverted install: the same parts bolted under the base's pad end, see above.
- Its lead (4 wires, 1.25 mm plug at the sensor) runs about 10 cm across the device to the controller (inverted install: about 10 cm, round the base's pad end).
- Setup per `03_sensor.md`: no calibration needed; optional app check for firmware version and tracking; leave the app's zones off.
- LD2410C (fallback only): top center of the opening, hallway side, aimed about 45 degrees down; settings in `03_sensor.md`.

## Power

- 12 V adapter at the outlet, 5.5 x 2.1 mm DC extension cable up to the ceiling. Tape the cable along the door trim.

## Safety

- Soft foam spider only, 60 g maximum, no hard eyes or wire legs at face height. Legs wider than about 50 mm may touch the limit switch at the top; trim or angle them down.
- Keep the drop clear of stairs, and of the swing of the door itself.
- 6 lb monofilament only (or put the elastic snubber back). Check the knots, the bead, the flap, and the line for nicks before each night.
- `disarm` (or unplug) when small children are expected to run through.

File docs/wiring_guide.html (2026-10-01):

# DropSpider Rev C.1: pinout and wiring guide

30-pin ESP32 DevKit V1 (the 38-pin NodeMCU-32S uses the same GPIO numbers). Every electrical part, where each wire goes, and which parts you can leave out. Source of truth: docs/02_electrical.md in the repo; if they disagree, the repo wins.

NEEDED | the machine does not work without it
ONLY IF | fit it only if a named bench test fails
SKIP | over-engineered for this build; leave it out

## 1. ESP32 pinout

Go by the GPIO number printed beside each pin, not its position. The same numbers work on the 30-pin DevKit.

ESP32 pin | Wire goes to | What it does | Watch out
VIN | buck converter OUT+ (5.0 V) | powers the board | never 12 V here
GND (any) | common ground | every ground ties together | adapter, expansion board, buck, ESP32, servo, radar, switch
GPIO26 | expansion board STEP | one pulse = 1/8 motor step
GPIO27 | expansion board DIR | motor direction | flip in software with dir, no rewiring
GPIO25 | expansion board EN | LOW = motor powered, HIGH = coils off
GPIO13 | servo signal (orange) | finger lock and release | not GPIO14: 14 pulses at boot and would drop the spider
GPIO16 (RX2) | LD2450 TX (yellow) | radar data in | TX crosses to RX
GPIO17 (TX2) | LD2450 RX (green) | radar data out | RX crosses to TX
GPIO32 | KW12-3 switch, NO leg | spider home: stops the rewind | pull-up is inside the chip; no resistor
GPIO33 | LD2410C OUT | backup radar, yes/no | optional, see section 4
GPIO0 | on-board BOOT button | manual test drop; hold for USB flashing | nothing to wire
GPIO2 | on-board blue LED | slow blink = armed and ready | nothing to wire
EN | on-board button marked EN | restart | nothing to wire

## 2. Power

From | To | Notes
12 V adapter + | expansion board VMOT, and buck IN+ | motor draws about 0.6 A while moving
12 V adapter - | expansion board GND, and buck IN-
buck OUT+ (5.0 V) | ESP32 VIN, servo red, LD2450 5V, LD2410C VCC if fitted | meter 5.0 V before connecting anything
buck OUT- | ESP32 GND, servo brown, radar GND, switch COM | one common ground

- Peak on the 5 V side is about 1 A (servo moving plus WiFi); the MP1584EN buck is comfortable to about 1.5 A.
- USB can stay plugged into the PC while 12 V is on.
- Ceiling install: run 12 V up a 5.5 x 2.1 mm DC extension. The adapter stays at the outlet.

## 3. Each part, wire by wire

### Stepper driver: TMC2209 on the expansion board

STEP, DIR, EN | GPIO26, GPIO27, GPIO25
VMOT, GND | 12 V adapter
DIP switches 1, 2, 3 | all OFF (1/8 step)
Current pot | 0.85 V pot top to GND, 12 V on, motor unplugged (= 0.6 A)
Orientation | driver's EN pin on the expansion board's EN position. Backwards destroys it

### Motor: NEMA 11, 4 wires, into the expansion board terminal

black / green | 1A / 1B
red / blue | 2A / 2B
Buzzes, will not turn | swap black and green
Never | plug or unplug the motor with 12 V on

### Finger servo (micro servo, SG90 in the parts list; an MG90S wires the same)

orange (signal) | GPIO13
red (+) | buck 5 V, not the ESP32's 3V3 pin
brown (-) | GND

### Limit switch: KW12-3 roller switch in the fairlead

COM | GND
NO | GPIO32
NC | nothing
Check | lift the flap by hand, watch the web page. Backwards: liminv 1. Then limit 1
Normal | reads open when the spider is parked; that is by design

### Radar: HLK-LD2450 (the trigger)

5V | buck 5 V
GND | GND
TX | GPIO16
RX | GPIO17
Plug | 4-pin, 1.25 mm pitch at the sensor. No OUT pin
Mount | flat on the wall above the door, hallway side, looking straight out

## 4. Parts to leave out: over-engineering check

Part | Call | Why
470 uF capacitor at the servo | SKIP | A micro servo stalls at well under 1 A, and it moves for a fraction of a second per scare. The buck converter already has its own output capacitors, and the ESP32 has its own 3.3 V regulator after VIN. Fit one only if the board restarts when the finger moves (the page's "Running for" clock resets). A restart does no damage: settings are kept, and the board never rewinds on its own at start-up, so the worst case is a spider left hanging that you rewind from the page.
74AHCT125 logic buffer | ONLY IF | Only if the motor stutters or will not turn on jog 1600 (commissioning step 4, item V1). Most TMC2209 boards take 3.3 V signals directly.
LD2410C backup radar | SKIP | The LD2450 does the job and tells approaching from leaving. The LD2410C is only a fallback if the LD2450 dies. Leave it in the drawer; three wires if you ever need it (5 V, GND, OUT to GPIO33).
Resistors or capacitors on the limit switch | SKIP | The chip's own pull-up and the firmware's debounce (ignoring the contact's first few milliseconds of chatter) cover it. Twisting the switch's two wires together is enough if the motor wires run beside them.
Bigger power adapter | SKIP | The 12 V 2 A adapter has three times the headroom the motor needs.
Capacitor at the driver's 12 V input | NEEDED | Not over-engineering: a stepper driver can be killed by a voltage spike on 12 V without one. Most expansion boards already have one (a round can near the power terminal). Look for it; if yours has one, nothing to add. Not checked on this expansion board.
Metering the buck (5.0 V) and setting the driver to 0.85 V first | NEEDED | The buck is a fixed 5 V MP1584EN, but a faulty or mislabelled module would kill the ESP32, servo and radar. The driver's factory current is too high for this motor.

## 5. Order to wire and power up

1. Buck on 12 V alone: meter it, 4.95 to 5.05 V.
2. Driver on 12 V, motor unplugged: set 0.85 V on the pot.
3. Power off. Wire the ESP32, servo, switch and radar. Motor still unplugged.
4. Power on: web page at dropspider.local shows "ready". Lift the switch flap and watch it change.
5. Power off, plug in the motor, power on, then jog 1600 with hands clear.

## Checked, and not checked

Checked 2026-09-25 | Pin numbers match the firmware (include/config.h) and doc 02. The board on COM13 is an ESP32 with 4 MB flash, on the home WiFi, updating by WiFi.
Not yet checked | Nothing on this sheet has been watched working with the motor, servo, switch or LD2450 connected. The LD2450 wiring is from the maker's pinout and doc 03; the firmware to read it is not written yet. The servo capacitor call is judgement, confirmed only when the servo moves on the bench without a restart.

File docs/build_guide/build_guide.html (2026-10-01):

# DropSpider build guide, Rev C.1

One page, top to bottom: wire the 30-pin ESP32 DevKit V1, assemble the device, power it up, then set it up and test it from its own web page. It covers the install you are building: the device turned over on two steel corner braces on the porch beam's inside face. The ceiling install is in doc 06 only. The repo docs (02, 05, 06, 07, 09) are the source of truth; if this page disagrees, the doc wins.

READY TODAY works with the firmware on the board now AFTER TASK 2 needs the LD2450 radar firmware PLANNED designed, not written yet

SOLDER soldered and heat-shrunk PLUG dupont jumper or the part's own plug SCREW screw terminal

The board runs the Rev C.1 firmware (flashed 2026-09-27): motor-led drop, release under load, seat move on lock. None of it has been watched working with the motor and the spool fitted yet (tests T1 to T8); run section 09 on the bench before anything goes overhead.

## 01Parts and tools

### Electrical parts (all already owned)

- 30-pin ESP32 DevKit V1 (the 38-pin NodeMCU-32S works too, same GPIO numbers)
- TMC2209 driver on the expansion board
- NEMA 11 stepper motor, 4 wires
- Micro servo (yours is an MG90, about 90 degrees of swing, checked 2026-09-27)
- KW12-3 roller micro switch
- HLK-LD2450 radar with its 4-pin 1.25 mm cable
- MP1584EN mini buck module, fixed 5 V out
- 12 V 2 A adapter with screw-terminal jack
- Dupont jumpers, 22 AWG wire for the 12 V run, heat shrink

Left out on purpose: the 470 uF servo capacitor, the 74AHCT125 buffer and the LD2410C backup radar. Each is only fitted if a named test fails.

### The two bearings: do not mix them up

- HF0612 one-way bearing (also called the clutch): 6 mm bore, 10 mm outside, 12 mm long, needle rollers inside. Spins free one way and locks the other. Presses into spool_body. This is what lets the spool run down behind the motor on the drop without ever overrunning it.
- 606ZZ ball bearing: 6 mm bore, 17 mm outside, spins both ways. Presses into the bracket's end plate and carries the far end of the rod.

### Tools

- Multimeter (needed before anything is connected)
- Soldering iron, solder, heat gun or lighter for heat shrink
- Small Phillips, small flat screwdriver (driver current pot)
- 1.5 mm and 2 mm hex keys (coupler set screws)
- Vise or clamp, CA glue (line knot only), blue threadlocker
- Drill with a 3.4 mm and a 7 mm (or 1/4 in) bit: five holes in the base
- Hot glue gun: expansion board and buck onto the pad, nothing else
- A phone or PC on the same WiFi as the board

## 02Board pinout, top view

Board face up, antenna end away from you, USB toward you. This is the 30-pin ESP32 DevKit V1: 15 pins a side, printed D25 for GPIO25 and so on, RX2/TX2 for GPIO16/17, VIN for the 5 V input. Go by the name printed next to the pin on your board, not by counting. On the 38-pin NodeMCU-32S the same GPIO numbers sit in other places.

Coloured pins are used. Pins marked on-board need no wire. D33 is left free unless the LD2410C backup radar is ever fitted. The BOOT button (GPIO0) is the manual test drop; it has no header pin.

## 03Power: one tree, no loops

12 V feeds the motor driver and the buck converter. The buck makes 5 V for the ESP32, the servo and the radar. Every ground is one ground.

Meter the buck on 12 V before any of the right-hand wires are connected: it must read 4.95 to 5.05 V. It is fixed at 5 V, but a faulty or mislabelled module would kill the ESP32, servo and radar at once.

## 04Every connection

One row per wire, both ends. Wire colours are a suggestion so the pictures match; what matters is which pin goes where.

Wire | From | To | Joints
step | ESP32 GPIO26 | expansion board STEP column, S row | PLUG PLUG
direction | ESP32 GPIO27 | expansion board DIR column, S row | PLUG PLUG
enable | ESP32 GPIO25 | expansion board EN column, S row | PLUG PLUG
signal ground | ESP32 GND (right row, next to 3V3) | expansion board, any one pin in the G row (all three G pins are joined) | PLUG PLUG
servo signal | ESP32 GPIO13 | servo orange | PLUG PLUG
switch | ESP32 GPIO32 | KW12-3 NO leg | PLUG SOLDER
radar data in | ESP32 RX2 (GPIO16) | LD2450 TX, yellow wire | PLUG PLUG
radar data out | ESP32 TX2 (GPIO17) | LD2450 RX, green wire | PLUG PLUG
5 V | buck OUT+ | 5 V rail on the protoboard: ESP32 VIN (solder bridge), servo red, LD2450 5V (red wire) | SOLDER PLUG
ground | buck OUT- | GND rail on the protoboard: ESP32 GND (solder bridge), servo brown, LD2450 GND (black wire), KW12-3 COM | SOLDER PLUG
12 V | jack + | expansion board VMOT, and buck IN+ | SCREW SCREW SOLDER
12 V ground | jack - | expansion board GND, and buck IN- | SCREW SCREW SOLDER
motor, 4 wires | NEMA 11 black, green, red, blue | expansion board 1A, 1B, 2A, 2B | PLUG
not wired | ESP32 GPIO33 | LD2410C OUT, only if the backup radar is ever fitted

### TMC2209 on the expansion board

DIR, STEP, EN each have three pins: S, V, G. The ESP32 wire goes on S: D27 to DIR, D26 to STEP, D25 to EN, the same order on both boards, so a 3-wire ribbon goes straight across. One ground wire from the ESP32 to any G. Leave every V empty. Pot to 0.85 V (pot top to GND), 12 V on, motor unplugged. Driver's EN pin on the expansion board's EN position. Motor order as printed on your expansion board; if it buzzes, swap black and green.

### KW12-3 roller switch

COM to the GND rail, NO to GPIO32, NC nothing. On your switch, from the lever's hinge end: COM, NO, NC (read off the part 2026-09-25). Confirm before soldering, meter on beep: at rest COM beeps to NC only; lever held, COM beeps to NO only. The leg that beeps both times is COM. Solder, then heat shrink each leg.

### Micro servo

The servo's 3-pin plug has red in the middle. Use three separate jumpers from the plug: orange to GPIO13, red to the 5 V rail, brown to the GND rail. Never red to the ESP32's 3V3 pin.

### HLK-LD2450 radar

Pin order per Hi-Link's manual (5V, RX, TX, GND); check the print beside the plug. TX to GPIO16, RX to GPIO17: they cross. Hi-Link asks for a 5 V supply able to give 200 mA; the buck is fine.

### MP1584EN buck, fixed 5 V

12 V in, meter on OUT+ and OUT-: it must read 4.95 to 5.05 V. Nothing to adjust. Some modules share one GND pad for IN- and OUT-; read the print. It runs warm at 1 A: keep it in the open, not under the ESP32.

## 05bProtoboard layout, one quarter

The ESP32 sits on one quarter of the snappable protoboard (17 holes across, 19 down). Underneath, the copper joins the holes in groups of three across, with a 15-hole rail down each side. So each ESP32 pin shares its group with two more holes: a male pin two holes outward is already connected to it, no wire needed. One rail carries 5 V, the other ground. This is the only protoboard: the expansion board and the MP1584EN buck are hot-glued beside it on the pad, each on its own wires.

Top view, parts side, USB end at the top edge so the cable reaches it. Faint gold bars show the copper groups on the underside. From the solder side everything is mirrored left to right: count holes from the rail, not from the edge you are looking at.

Part on the protoboard | Where | Why there
2 x 15-pin female socket strip | columns 3 and 13, rows 2 to 16 (10 holes apart) | ESP32 unplugs in seconds; one board has already failed
Signal male pins | column 15 (VIN side) and column 1 (3V3 side), same row as their ESP32 pin | same copper group as the ESP32 pin, no wire; one pin per wire, servo wires separate
5 V rail, male pins | right rail, rows 13 to 15, plus a bridge at row 2 | 5 V in from the buck's OUT+, servo red, LD2450 5V; servo current never passes through the ESP32
GND rail, male pins | left rail, rows 12 to 15, plus a bridge at row 3 | GND in from the buck's OUT-, servo brown, LD2450 GND, KW12-3 COM
Nothing else | - | switch and radar need no resistors; servo capacitor and logic buffer only if a test fails (2 free rail holes kept for the capacitor)

Check before soldering: drop the ESP32's header pins into the board. They must land in columns 3 and 13, 10 holes apart. That spacing is read off your photo, not measured; if your pins land 9 holes apart, use columns 3 and 12 and move the right-hand pins one column in.

## 05Soldering, in order

### Header pins on the ESP32

1. Solder full 15-pin header strips down both sides, pins pointing down from the underside, so every jumper plugs on. If you only do the ones this build uses: VIN, GND, D13, D27, D26, D25, D32 on the top row (the row with VIN), and GND, RX2, TX2 on the other row. Push the strip into a breadboard to hold it straight, solder one pin at each end, check it is square, then the rest. Each joint a shiny cone, no bridges to the next pin.

### Wires on the MP1584EN

2. Tin the four pads. IN+ and IN-: two 22 AWG wires long enough to reach the 12 V jack. OUT+ and OUT-: two wires ending in female dupont plugs for the protoboard's "5 V in" and "GND in" pins. Heat shrink every joint.

### Meter the buck before it goes in

3. IN wires into the 12 V jack's screw terminals. Meter on the OUT wires: 4.95 to 5.05 V. Unplug.

### Protoboard: sockets, pins, bridges

4. Follow the protoboard drawing in section 05b: two 15-pin female sockets for the ESP32, single male pins beside the used signals and on the two rails, and two solder bridges (a blob of solder, or a short bare wire, across the gap between two neighbouring holes) that tie the ESP32's VIN to the 5 V rail and its GND to the GND rail.

### 12 V and 5 V wiring

5. The jack's screw terminals take two wires each: + to the expansion board's VMOT and to the buck's IN+, - to the expansion board's GND and to the buck's IN-, 22 AWG. The buck's OUT+ and OUT- plug onto the protoboard's "5 V in" and "GND in" rail pins.

### KW12-3 legs

6. Heat shrink on, one wire each to COM and NO, solder quickly (a slow iron melts the switch body), shrink. Female dupont ends: COM to the GND rail, NO to the LIMIT pin. Twist the two wires together along their length.

### Check with the meter before power

7. ESP32 out of its sockets. Continuity mode: 5 V rail to GND rail must NOT beep. Each signal pin to its socket hole must beep. No signal pin may beep to a rail. KW12-3 NO to COM beeps only while the lever is pressed.

## 06Mechanical assembly

Condensed from doc 05. Pictures are the CAD renders from the repo; new parts in each step are in full colour.

Exploded view of every part along the rod

Everything on one 6 mm rod, motor to bearing: coupler, spacer A, ratchet disk, spool body with the HF0612 one-way bearing inside it, spacer B, 606ZZ ball bearing.

Every part on the rod cut in half, showing the HF0612 one-way bearing inside the spool

The same parts cut in half along the rod. The orange sleeve inside the spool is the HF0612 one-way bearing: flush with the spool flange, its last 2 mm sitting in the ratchet disk's center hole.

### Stack the spool, then press the one-way bearing in

1. Stack first, bearing last: spool_shield (flat 64 mm disc, either face) on the spool's flat face, then the ratchet disk, its flat face (no counterbores) on the shield. 3x M3x8 through all three into the spool, snug. All three must sit flat together with no gap at the rim; the shield keeps the line off the teeth. Then press the HF0612 one-way bearing (the clutch; the small 10 mm one with needle rollers, not the 606ZZ) in from the spool's flange side, through all three holes, with a vise or clamp, until flush with the flange. The holes are 10.3 mm, a firm press (10.0 would not take it, 10.2 was tight, 10.7 was loose). Test on a spare rod: spins free one way, locks the other. Look from the boss side, where the ratchet disk goes (it faces the motor, so this is the view from behind the motor): free must be clockwise, locked counterclockwise. If not, press it out and flip it. This is the Rev C.1 fix.
  What that gives you: turning clockwise (seen from behind the motor) the rod drives the spool. That is the winding direction, so the finger slides up each tooth's long curved face and clicks off the tip; no tooth is ever driven into the finger. Only the spider's weight, pulling counterclockwise, brings a steep face against the finger, and that is the hold.

Ratchet disk and finger seen from behind the motor, showing which way the rod drives the spool

### Line

2. Anchor it with a toggle, not glue alone: drill a 1 mm hole straight through the barrel's skin (it is 1.6 mm thick) into one of the spoke windows, in the middle of the barrel's width and midway between two spokes. Push the line in from outside, fish it out of the window's open end at the flange face, tie it round a 10 mm stub of 1.75 mm filament (a double overhand), and pull it back so the stub lies across the hole inside the window. A drop of CA on the knot. The stub cannot pull through a 1 mm hole, so the line cannot slip round the barrel even if the spider runs the line out. Then wind clockwise (seen from behind the motor), the first turn over the line's tail. No elastic, no braid: the mono's own stretch is the shock absorber.

### Ball bearing and motor

3. 606ZZ ball bearing (the 17 mm one) into the end plate. The seat is drawn 17.0 mm from 2026-09-27 (it was 16.8, which would not take the bearing even heated); the print comes out 0.1 to 0.2 small, which is the press. On a bracket printed before then, sand the seat with rolled sandpaper until the bearing presses in. If the bearing ends up loose (heating it in can soften the seat), fit bearing_retainer on the end plate's outside face: drill two 2.5 mm pilots through the end plate using the retainer's holes as the guide, then 2x M3 x 6 to 8. The rod runs on through its 12 mm hole, about 14 to 17 mm past it; that is expected. Motor on the outside of the motor plate, 4x M2.5x6, wires toward the base.

Step 1 render

### Coupler

4. 5 mm side onto the motor shaft until it stops, blue threadlocker, tighten. 6 mm side loose.

Step 2 render

### Measure, then stack

5. Motor plate outer face to the coupler's free end: 30 mm means use spacer_A_6mm as is; 27 to 29 mm add shims. Hold spacer A, spool (ratchet toward the motor), spacer B in line in the frame. Owner's build (2026-09-29): snug but not tight took about 4 mm of shim on the motor side of the spool and 5 mm on the 606ZZ side. Shim to your own frame the same way, then check the ratchet disk still sits between the finger's faces.

Step 3 render

### Rod in

6. From outside the 606ZZ plate, through everything into the coupler until it bottoms; turn the spool its free way as the rod enters the needles. Threadlocker, tighten. Check: spool free clockwise seen from behind the motor, counterclockwise drags the motor. End play no more than 0.5 mm.

Step 4 render

### Servo and finger

7. Servo into the tower pocket, spline toward the spool, two tab screws. No horn: the finger presses straight onto the spline later, at 90 degrees, during calibration (section 09), and the horn screw holds it.

Step 5 render

Lock detail section

  Locked: finger level in the teeth, the tooth pushes it up onto the ledge, not into the servo.

### Printed parts for this install

8. fairlead_base and fairlead_flap_inv (fairlead v2, 2026-09-28: the switch sits above the flap, the flap is the lowest point; the older fairlead_flap has no tab and does not fit), ld2450_fork_screw and ld2450_cradle. fairlead_body is the ceiling install's and is not used.

### Holes in the base

9. A bracket printed from bracket.stl dated 2026-09-28 or later has all five holes printed in: the 7 mm line pass-through and four 3.4 mm screw holes. Skip this step. Only on an older print: print cad/bracket_footprint_inverted.svg at 100% (its 100 mm bar must measure 100), lay it on the base's flat outer face, printed side up, lined up with the base's outline, and drill through the blue crosses. The dashed outlines show where the fairlead block and the radar fork will sit; the block sits beside the long cutout under the spool, not over it. Five holes: 7 mm for the line (a 1/4 in bit is close enough), 3.4 mm x2 for the fairlead block (the pair nearest the spool on the servo side), 3.4 mm x2 for the radar fork (at the pad end). Sand the 7 mm hole smooth inside and on both edges: the line runs through it.
  Every print, new or old (2026-10-01): your build has the servo end at the beam, so the radar moves to the pad end. Drill 2x 3.4 mm at the pad end, 8 mm in from the base's end, 38.5 and 72.5 mm from the motor end (the template marks them). The printed radar holes at the servo end stay empty.

### Switch and flap onto the block

10. Solder the switch wires first. Clear the block's bore with a 3 mm drill by hand. KW12-3 on the block's outer side (away from the rod), lever and roller down, legs up: 2x M2 x 12 screws through the switch, threading straight into the plastic (no nuts), snug. Flap on an M2 bolt, 20 mm, in from the rod side through the knuckle and threaded into the hinge boss, not clamped; its tab goes under the roller. At rest the flap hangs a little nose-down and the roller sits clear of the tab. Lift the flap's free end by hand: it touches the roller, clicks, then stops flat against the block.

### Block onto the base

11. Flat face of the block against the base's outer face, its bore under the 7 mm hole. 2x M3 x 12 from inside the base (heads on the device side), cutting their own thread into the block. Snug, not tight: the thread is plastic. Look down through the 7 mm hole: you must see straight through the bore. No glue.

Fairlead block under the base seen from below: flap, bead, switch and the two screws

### Thread the line

12. Wind the line clockwise seen from behind the motor, and lead it off the spool's servo side, down through the 7 mm hole and the block's bore, then slide it into the flap's slot from the flap's free end. Below: 8 mm bead, swivel, spider (60 g at most).

### Measure the line

13. Unwind fully. Barrel knot to bead, line straight but not pulled: that number is Line length on the web page.

### Check by hand

14. Pull the bead up against the flap: the flap swings toward the base, the switch clicks, the flap stops flat against the block. That is "spider home". Let go: the flap drops back to its rest stop and the switch opens.

### Radar mount

15. No glue. ld2450_fork_screw under the base at the pad end (the end away from the beam), on the two new holes, ears hanging down: 2x M3 x 10 up through the fork and the base, nuts inside; the two nuts sit inside the base 8 mm from its end, under the board's edge: keep that strip clear, or lift the board on foam tape 4 mm thick. Put ld2450_cradle's round knuckle between the ears and push an M3 bolt (25 to 30 mm) through, nut on the far side, snug enough to hold an angle. The radar looks along the base toward the beam (the servo end): the cradle's face plate with the windows faces the beam, and the open back with the pin headers faces away from it. Slide the LD2450 up into the grooves from the bottom, antenna side against the face plate (the side with the gold antenna pads, against the windows; Hi-Link: the antenna side faces the area to be watched), pin-header end last so the headers sit at the bottom, open at the back; a small zip tie round the cradle's bottom end keeps it from sliding out. Tilt 50 degrees down to start; set it on site (section 11).

### Controller on the pad

16. The pad is the flat area at the motor-plate end (x -88 to -36), on the device side of the base, now facing up. The protoboard with the ESP32 on it, foam tape or zip ties through the x = -80 holes. The expansion board and the buck hot-glued beside it, clear of the spool. Switch and radar leads run round the base's pad end (the servo end is against the beam) and back to the board, about 15 cm and 10 cm, tied to the base so the spool cannot catch them.

## 07First power-up, one layer at a time

### Buck alone

1. 12 V on, nothing on the 5 V side. Meter reads 4.95 to 5.05 V (fixed 5 V module, nothing to adjust).

### Driver current

2. Motor unplugged, 12 V on. Meter from the pot's metal top to GND: turn to 0.85 V (that is 0.6 A). Factory setting is about 1.2 V, too high for this motor.

### Everything but the motor

3. Power off. Plug in the ESP32, servo, switch, radar. 12 V on. The blue LED blinks slowly when armed and ready. The finger servo swings to its lock angle once at start-up: keep fingers clear.

### Motor last

4. Power off, plug in the motor, power on. Never plug or unplug the motor with 12 V on.

## 08The web page is the control panel

The board serves its own page. On a phone or PC on the same WiFi, open http://dropspider.local. If that name does not resolve (some Android phones), use the address the board got from the router: type wifi in the Console, or look at the top line of the page (on 2026-09-25 the new board got 192.168.1.138; the router may change it). If the board cannot join the WiFi within 15 s it makes its own network, DropSpider-setup (password dropspider), and the page is at 192.168.4.1.

Every button sends a text command, and the Console card shows everything the board says, so the page and the USB console always agree. The page refreshes itself a little faster than once a second. READY TODAY

Status

ready

armedswitch open, spider not homeradar: clear

Drops so far0

Last fired by-

Last rewind-

Last drop, measured by the rewind-

Running for2 min 14 s

Run

Drop it nowDisarmStopMotor and servo offClear fault

Bench: finger servo

85 deg holding

-5 deg-1 deg+1 deg+5 degGo to lock angleGo to release angleStore as lockStore as release

Bench: motor

-1 turn-1/8+1/8+1 turnRewindLockRelease

Settings

Finger lock angle85

Line length636

Limit switch fitted1

Save settingsFactory values

Console

> jog 200
[jog] ran 200 steps
[done] jog (motor stays on)
> off
[done] off: motor and servo off

Network

Network name, passwordSave and restart

Firmware

Update over the networkOpen the update page

What the chips mean: armed means a radar signal may fire it. Nothing drives the radar input today (the LD2450 needs task 2; the LD2410C backup is not fitted), so the radar chip always reads clear and only Drop it now or the BOOT button fire it. Motor powered appears whenever the driver is on. Spider home is the limit switch. A red chip is a fault, with its reason; three in a row and it stops until you press Clear fault.

## 09Calibrate from the web page, in this order

Bench first: device base-down on the table, slid out over the edge until the fairlead block and the radar under the base hang free, held or clamped, so the line can drop about 0.7 m to the floor. Any bench move disarms the radar on purpose; step 10 re-arms it. Record each result in the commissioning log.

### Page loads READY TODAY

1. State reads "ready" or "waiting for the doorway to clear". The Console card shows the start-up lines.

### Limit switch reads right READY TODAY

2. Lift the fairlead flap by hand and let go, watching the status chip change between "reads pressed" and "reads open". If it is backwards, type liminv 1 in the Console. Then set Limit switch fitted to 1 and press Save settings.

### Motor turns cleanly READY TODAY

3. Hands and line clear. Bench: motor, +1 turn then -1 turn. One smooth turn each way. Stutters or buzzes: this is the logic-level check (open item V1); see doc 02.

### Finger angles READY TODAY

4. Set 2026-09-27 and saved: lock 85, release 50 (finger on the spline, ratchet not yet on the rod). Recheck with the ratchet in place: Go to lock angle, the finger must sit level in the teeth; Go to release angle, it must be clear of them. If not, nudge, Store as lock or Store as release, Save settings.

### Rewind direction READY TODAY

5. Spider hanging. +1/8: the spool should wind the line up. If the motor turns but the spool slips, set Rewind direction to the other value and try again. If neither way winds, the HF0612 one-way bearing is still in the Rev C direction: flip it (assembly step 1).

### Line length READY TODAY

6. First set Drop distance to no more than the line minus 102 mm (636 line: 534), or the page refuses the new line: the factory drop, 620, only fits the old 720 line. Then enter the measured number in Line length, Save settings.

### Release under load, drop, rewind, lock READY TODAY

7. The Rev C.1 sequence: the motor winds the spool back 1/12 turn while the finger swings out, then runs the drop under power, then rewinds until the switch clicks, then eases the spool onto the finger. Not yet run with the motor and spool fitted. Its settings: drop distance (dropmm), drop speed (droprpm), speed-up and slow-down rates (dropacc, dropdec), finger release time (relms). Tests T1 to T8.

### Five full drops READY TODAY

8. All complete, no tangles, finger always relocks. After the lock the switch reads open: correct by design, the firmware remembers the spider is home from the last cycle.

### Radar live view AFTER TASK 2

9. See section 10. Walk toward the door, away, and across; confirm it fires only walking in.

### Arm and save READY TODAY

10. Press Arm, then Save settings so it stays armed after a power cut.

### Planned: a Calibrate card that walks these steps PLANNED

One card on the page that shows the current step, what to do with your hands, a single button that runs the move, and Pass or Fail buttons. Results are written to the board's log so they can be copied into the commissioning log. This replaces the test console command on the backlog: same steps, but on the phone in your hand at the bench.

## 10Live sensor readings in the browser

Reading | Where on the page | Status
Limit switch pressed or open | Status chip, about once a second | READY TODAY
Finger servo angle and whether it is holding | Bench: finger servo | READY TODAY
Motor powered, last rewind steps, measured line length | Status card | READY TODAY
Every event the board logs | Console card | READY TODAY
Radar yes/no | Status chip. Today it reads GPIO33, the unfitted LD2410C's pin, so it always says clear | AFTER TASK 2
LD2450 people: position, speed, arrival time | Radar card, about 5 times a second | AFTER TASK 2
"Would fire now" lamp | Radar card | AFTER TASK 2

Design for task 2, drawn with example numbers, not live data. The map only updates quickly while the card is open, so an idle page costs the board nothing.

## 11On the beam: braces and placement

Your plan, approved 2026-09-27, doc 06. The device upside down, base at the bottom, sitting on the flat legs of two 6 in steel corner braces whose other leg stands up the beam's inside face. Checked in the CAD model; not yet built or hung.

Device turned over on two corner braces on the beam's inside face, servo end at the beam, line out through the base, radar under the pad end

Point (8 ft porch ceiling, beam 10 in deep) | Height
Porch ceiling | 2440 mm (96 in)
Bottom of the front beam | 2184 mm (86 in)
Device's base | about 2280 mm (160 below the ceiling)
Bead at home | about 2244 mm (196 below the ceiling)
Spider, retracted | hidden behind the beam only if it is 28 mm tall or less
Spider at rest after the drop | 1550 mm (61 in)

- Braces: yours to place and drill. Upright legs up the beam's inside face, tops about 8 mm under the ceiling; flat legs under the base. A bolt through the base is clear between 24 and 55 mm from the rod's centre line on the servo side, at either end of the base; at the motor end also within 12 mm of the rod. Never within 20 mm of the rod at the 606ZZ end: the bearing plate stands there.
- Rod parallel to the beam, the servo end against the beam (your build, 2026-10-01). The line falls 54 mm out from the beam's face, centred on the walkway. A spider wider than about 10 cm will brush the beam; yours is about 8 cm, about 14 mm to spare while it hangs still. Watch the first drops for it swinging into the beam.
- LD2450: under the base at the pad end, the far end from the beam, looking along the device toward the beam and down. Nothing on the device blocks its view, and its centre line passes under the beam (409 mm below the ceiling against the beam's 254). Start at 50 degrees; if it fires late or fires on nothing, go to 55 or 60 (the cradle clears every part from 20 to 90). Check on the bench: walk across in front of it and X must change.
- Not through metal. The radar sees through wood, drywall and plastic, but aluminum siding or trim blocks it completely, however thin. If the beam is clad in aluminum, the radar only sees people under the beam's bottom edge, and the metal can bounce back phantom targets. Tilt steeper.
- The spider hangs inside the radar's view. If the radar counts it as a person, the device would sit waiting for the doorway to clear after each scare; the first walk test shows it.
- 12 V adapter stays at an outdoor-safe outlet; DC extension up the post. Keep the electronics out of blowing rain.

### Line length for your porch

line = (ceiling - 196) - (rest height + spider height + 30) + 72

All in mm. Example: (2440 - 196) - (1550 + 100 + 30) + 72 = 636. Tie it long, enter it as Line length, then shorten on site until the resting height is right. Order on the day: device finished on the bench (section 06), braces to the beam, device onto their flat legs, bolted through your holes.

## 12On site, then arm

### Five drops in place READY TODAY

1. Adjust Line length (and drop distance) until the spider stops at face height.

### Walk tests AFTER TASK 2

2. Walk in from 3 m: it fires and the spider arrives as you reach the doorway. Walk away, walk across, stand still: no drop.

### No double scare READY TODAY

3. After a scare, stand in the doorway: nothing until you leave and 20 s pass (Lockout after a scare).

### Before each night

4. Check the knots, bead, flap and the line for nicks. Soft foam spider only, 60 g at most. Press Disarm, or unplug, when small children are about to run through.

How this was checked, 2026-09-25; inverted install, bearing seat, flap and aluminum note added 2026-09-27; separate power board removed, inverted fairlead steps and firmware status 2026-09-28; page turned over to the inverted install, web page picture matched to src/web.cpp, finger angles and servo from docs/commissioning_log.md, 2026-09-28. Inverted install numbers from python cad/inverted.py (every check passes, radar cradle clear from 20 to 90 degrees; servo end at the beam and radar at the pad end from the owner's photo, 2026-10-01). Radar and metal: Hi-Link's LD2450 manual and install guides, plus the skin depth of aluminum at 24 GHz. Pin numbers read from the firmware (include/config.h) and doc 02. 30-pin header order from the Last Minute Engineers ESP32 DevKit pinout, checked against the pin names in doc 02. LD2450 pin order and 200 mA supply from Hi-Link's manual. Assembly, placement and heights from docs 05, 06 and 09; inverted heights, brace bolt zones and line formula from doc 06 and cad/inverted.py. Web page cards copied from src/web.cpp. Board on COM13 read by esptool: ESP32-D0WD-V3, 4 MB flash; flashed by the standard USB upload and joins the home WiFi at 192.168.1.138.

Pin names in the drawing checked against a photo of the board in use (30-pin DevKit V1, micro-USB, EN and BOOT buttons by the USB), 2026-09-25. Not checked. The servo has been watched moving and holding (2026-09-27); nothing else here has been watched working with the motor, switch or radar connected, and the inverted install has not been built. Everything marked AFTER TASK 2 or PLANNED does not exist on the board yet; the radar card is a design drawn with example numbers.

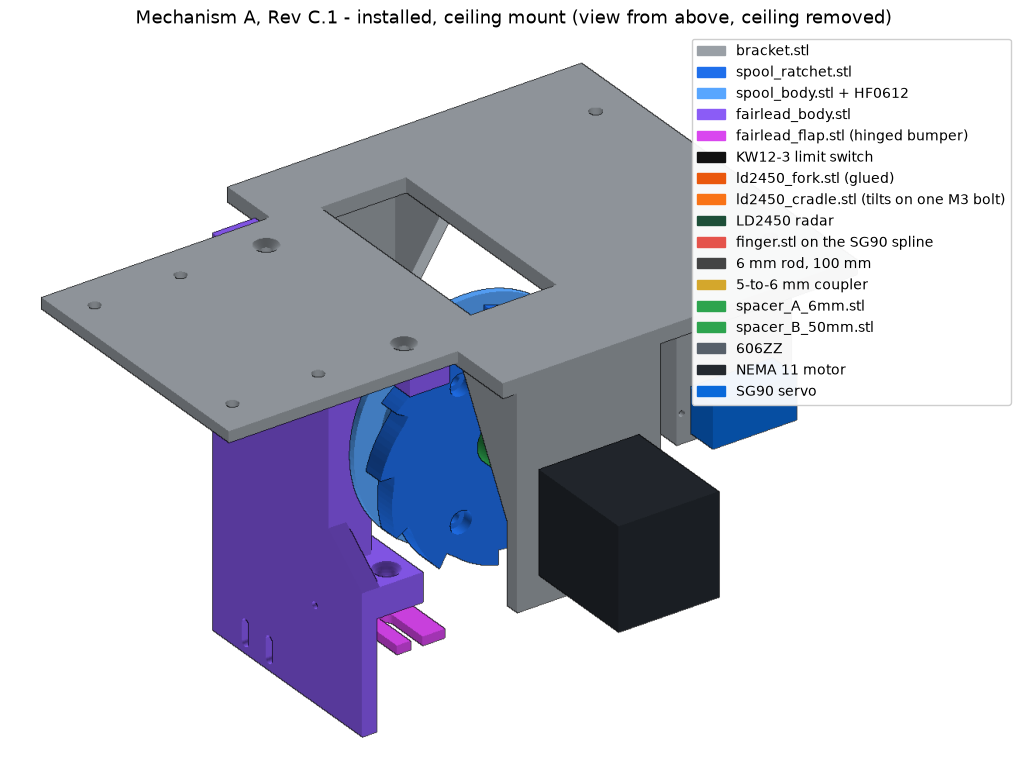
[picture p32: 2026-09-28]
docs/img/assembly_iso_top.png

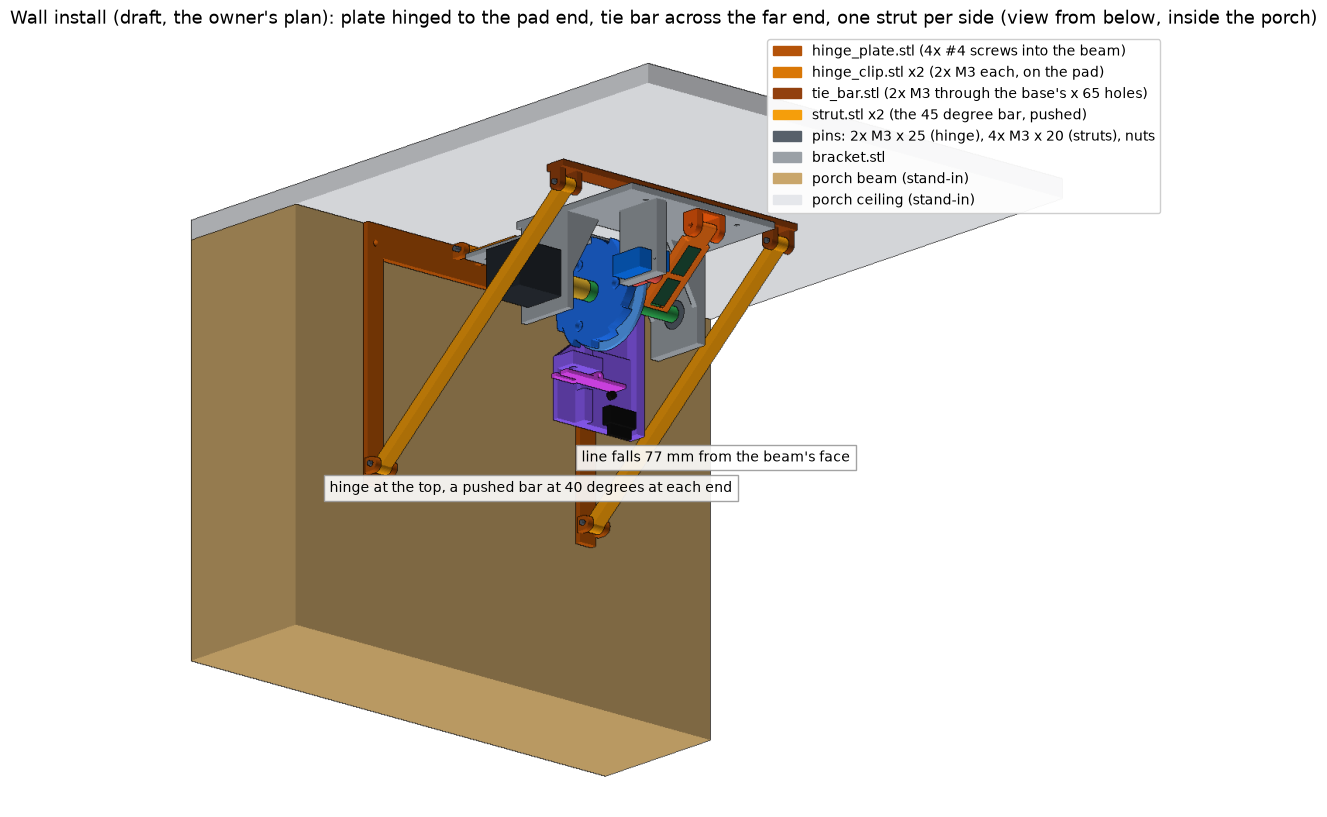
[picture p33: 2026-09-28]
docs/img/wall_install.png

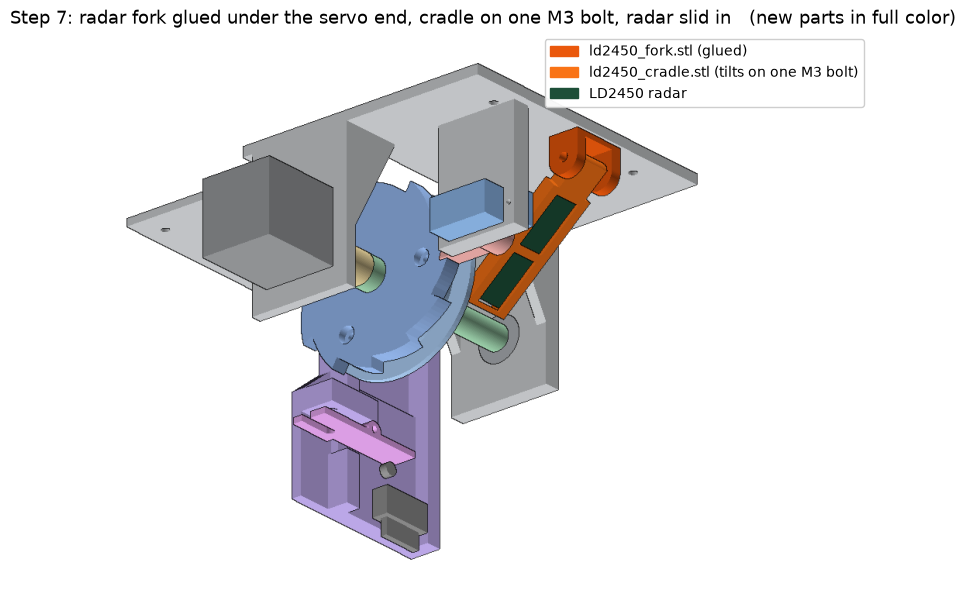
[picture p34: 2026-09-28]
docs/img/step7.png

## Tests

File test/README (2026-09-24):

PlatformIO unit tests go here (pio test). None yet.

Hardware tests are run from tools/console.py against the real board and recorded in docs/commissioning_log.md.

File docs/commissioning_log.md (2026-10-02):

# Commissioning log

Every bench and install result, in order. One row per attempt, failures included. Steps refer to `07_commissioning.md`; open items to `08_open_items.md`.

| Date | Step | Result | Value set | Evidence |
|---|---|---|---|---|
| 2026-09-24 | build | PASS | platform espressif32@6.7.0, board nodemcu-32s | `pio run` SUCCESS, 46% flash, 17% RAM, no warnings in project code |
| 2026-09-24 | board check (V12) | NOT DONE | - | COM13 = Silicon Labs CP210x USB chip. esptool could not put the chip in flash mode ("Wrong boot mode detected (0x13)"), twice. Needs BOOT held |
| 2026-09-25 | board check (V12) | PASS | - | Board put in flash mode by hand (hold IO0, tap EN, let go of IO0). esptool through `tools/esptool_noreset.py`: ESP32-D0WD-V3 rev 3.1, dual core, 4 MB flash, MAC d4:e9:f4:64:e1:1c. The normal esptool port open held the chip in reset, which is why the 2026-09-24 tries failed |
| 2026-09-25 | USB flash | PASS | Rev C firmware (pre C.1) | 904144 bytes written, hash verified, restarted by RTS |
| 2026-09-25 | 3 | PASS | - | `status` over USB: state ready, sensor 0, driver off, servo off. What is wired to the board was not recorded |
| 2026-09-25 | 3a (V11 part) | PASS | DHCP | Joined MAINFRAME007 at 192.168.1.16; `http://dropspider.local/api/status` answered from the bench PC. Network firmware update not tried yet |
| 2026-09-25 | V11 network update | PASS | - | `pio run -e ota -t upload` to dropspider.local: 88 s, "Result: OK". Board back on the network 27 s later, uptime reset, state ready. No button presses needed |
| 2026-09-25 | update script, WiFi | PASS | - | `scripts/update_firmware.bat wifi`: first run failed at the upload (no retry then), next runs "Result: OK" in about 28 s. Retry added: up to 3 tries. USB path not yet run |
| 2026-09-25 | first new board | FAIL | - | First replacement board on COM13 (probably the same 30-pin model, not confirmed): USB chip seen, ESP32 silent on every try (no boot message on EN, no flash-mode reply). Set aside; likely faulty |
| 2026-09-25 | board swap to 30-pin DevKit V1 (V12) | PASS | - | esptool: ESP32-D0WD-V3 rev 3.0, 4 MB flash, MAC 3c:e9:0e:88:82:b8. Enters flash mode by itself: plain `pio run -t upload` and `scripts/update_firmware.bat usb` both flashed it, hash verified. Pin names checked against Joe's photo |
| 2026-09-25 | 3, 3a | PASS | DHCP | `status` over USB: ready. Joined MAINFRAME007 at 192.168.1.138; dropspider.local answers |
| 2026-09-25 | V11 on the 30-pin board | PASS | - | `scripts/update_firmware.bat wifi`: first try, "Result: OK" in 30 s; back on the network at 192.168.1.138, uptime reset, state ready |
| 2026-09-27 | build, Rev C.1 firmware (task 1) | PASS | - | `pio run` SUCCESS, 45.9% flash, 17.1% RAM, no warnings in project code. Motor-led drop, unload on release (M2), seat move on lock, V14 home memory, new settings dropmm, droprpm, dropacc, dropdec, relms |
| 2026-09-27 | network update, Rev C.1 | NOT DONE | - | Board not reachable: `dropspider.local` did not resolve, 192.168.1.138 did not answer, no COM13 on the PC. Board off or unplugged |
| 2026-09-27 | network update, Rev C.1 | PASS | - | Board powered, no motor or servo connected. `pio run -e ota -t upload`: "Result: OK" in 35 s. Board back at 192.168.1.138, boot line "Rev C.1 ready", all 15 settings at defaults incl. dropmm 620, droprpm 500, dropacc 120000, dropdec 60000, relms 250; `help` prints in full; home=unknown (limit not fitted). No USB port showed on the PC, so the USB path was not used
| 2026-09-27 | T1 to T8 | NOT RUN | - | waiting on the Rev C.1 flash |
| 2026-09-27 | V17 servo type | PASS | - | `servo 90`, `servo 30`, `servo 150`, nothing on the spline: owner saw it move and hold (positioning servo, not 360). Strained against its own stop at 150, switched off. Owner calls it an MG90 with about a 90 degree sweep |
| 2026-09-27 | 5, finger angles | SET | setlock 85, setrel 50, saved | Owner, on the bench with the finger on the spline: 85 = finger level, resting on the stop block; 50 = release, his call. Ratchet not on the rod, so clearance of the teeth not yet seen; T3 checks it |
| 2026-10-01 | network update, new driver pins | PASS | - | DIR 27, STEP 26, EN 25. `pio run -e ota -t upload` SUCCESS in 56 s; board back on 192.168.1.137, uptime 27 s at the first status read |
| 2026-10-01 | 4, V1 logic level (motor) | PASS | - | Driver pot 0.825 V (owner's meter). `jog 1600` twice from the web page: owner saw one smooth turn each time. `jog -1600` sent over the network: log `[jog] ran -1600 steps`, no fault (turn back not watched by the session). No buffer needed |
| 2026-10-01 | 4, motor direction | PASS | dir 1 (unchanged) | Owner watched `jog` + turn: rod clockwise seen from behind the motor, the winding direction. No change to `dir` |
| 2026-10-01 | 3b, limit switch | PASS | liminv 0, limit 1, saved | Status read every 0.3 s while the owner pressed the flap: reads 1 while held (holds of about 3 to 4 s seen), 0 at rest, so no `liminv` needed. The log also showed 4 short closes (0.4 to 1.1 s) and 6 holds where the owner reported pressing twice: early presses or bounce, not yet ruled out as noise |
| 2026-10-02 | 5, finger angles with the ratchet on the rod | PASS | setlock 85, setrel 50 (unchanged) | No line. `lock`: owner saw the finger level in a tooth gap; spool turned by hand stops hard counterclockwise; clockwise pushes the unpowered finger out of the way (no click, expected: the finger is held only by the servo). `rel`: finger clear of the teeth; with the motor on, spool free clockwise, counterclockwise turns the motor through the HF0612 with stepping resistance (clutch locks that way, correct). Board stayed up through `rel` (uptime continued). Limit switch reads pressed on the bench: the flap rests on the roller with the device the right way up |

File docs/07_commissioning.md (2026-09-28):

# 07 - Commissioning (bench first, then installed)

Do every step on the bench, device base-down, spool hanging over the table edge so the line can drop about 0.7 m. Each step has a pass condition; do not go on until it passes. Record every result in `commissioning_log.md`.

Commands can be typed in three places, all equivalent: the web page's Console card (`http://dropspider.local`), the USB serial console at 115200, or `python tools/console.py COM13 <command>`. The web page's buttons send the same commands.

Step numbers 1 to 14 are unchanged from Rev C so the open-items table still points at the right step. Steps 3a and 3b are new. Rev C.1 changed steps 7, 8 and 10 for the motor-led drop; the full new test list T1 to T8 is in `M1_fix_handoff.md`.

| # | Do | Pass |
|---|---|---|
| 1 | 12 V on, nothing else connected: meter the buck output | 4.95 to 5.05 V |
| 2 | Motor unplugged: meter TMC2209 Vref (pot top to GND) | 0.85 V |
| 3 | Everything wired except the motor. Power up. | Console prints `ready`, `status` shows sensor 0 with nobody near |
| 3a | Open `http://dropspider.local` on a phone or PC on the same network (or the address `wifi` prints) | Page loads, state reads "ready" or "waiting for the doorway to clear", the Console card shows the log |
| 3b | Limit switch wired, `limit` still 0. Press its lever by hand, then let go, watching the status chips | Chip reads "reads pressed" while held and "reads open" when let go. If backwards: `liminv 1`. Then `limit 1`, `save` |
| 4 | Power off, plug in the motor, power on. `jog 1600` then `jog -1600` | One smooth turn each way (**V1 logic-level check**) |
| 5 | `off`. `servo 90`, then `servo 30` (or the nudge buttons) | Finger level in the teeth at 90, clear of the teeth toward the floor side at 30. Adjust with `servo <n>` until true; `setlock` / `setrel` the values (or Store as lock / Store as release), then `save` |
| 6 | With line wound and finger at lock, pull the spider down by hand | Spool does not turn; finger pressed onto the ledge, not bending the servo |
| 7 | `rel` (Rev C.1: motor on, winds about 1/12 turn while the finger swings out), then `drop` | `rel`: finger clears the teeth with no servo buzz. `drop`: motor spins, spider falls fast and stops at the set height, short of the line's end (no bounce off the end) |
| 8 | `rewind` | Spool winds the line up. If the motor turns but the spool does not (clutch slipping): `off`, `dir 0` (or 1) and repeat. If neither direction winds, the HF0612 is in the Rev C direction: flip it (05 step 4) |
| 9 | Watch the end of `rewind` | With the switch on: the bead lifts the fairlead flap, the switch clicks, the motor stops at once, no buzz; console says "stopped by the limit switch". With the switch off: the flap bottoms on the fairlead, motor buzzes briefly (skipping), then stops |
| 10 | `lock` | Finger goes in, motor eases the spool down onto a tooth, motor goes off, spider drops no more than about 13 mm and stays. The flap drops back and the switch reads open: correct by design (doc 09, V14) |
| 11 | `line <measured mm>`, `save`, then `drop` five times | All five complete, no tangles, finger always relocks. With the switch on, "Line length measured by the switch" on the page is within about 40 mm of `line` |
| 12 | `arm`, `save`. Walk toward the door from 3 m away, then walk away, then walk across the hallway | Fires only when walking toward the door, spider arriving as you reach the doorway. LD2450 tests S1 to S5 in `handoff_sensor_bearings.md` |
| 13 | Stand still in front of it after a scare | No second scare until you leave and 20 s pass |
| 14 | Hardware check after 20 cycles | Coupler set screws tight, no white stress marks on the finger or ledge, knot intact, flap swings freely on its pin, switch roller not bent, no groove worn in the fairlead bore |

Bench motion commands disarm the radar on purpose. Step 12 re-arms it.

Then mount per `06_installation.md` and repeat steps 11 to 13 in place, adjusting `line` for the resting height.

## If something fails

| Symptom | Likely cause | Fix |
|---|---|---|
| Motor buzzes, no turn | one coil reversed | swap black and green |
| Motor erratic or silent but holding | 3.3 V logic into 5 V driver | add the 74AHCT125 buffer (see 02) |
| Drop is slow or stutters | motor losing steps at `droprpm`, or spool rubbing a spacer | lower `droprpm`; check end play; lighter spider |
| Spider slams at the bottom | motor lost its grip while stopping | lower `dropdec`; lighter spider |
| Finger will not release, servo buzzes | tooth pinning the finger (M2) | release must run with the motor winding; check the unload move in the log |
| Spider drops at power-up | finger not seating at boot, or servo on GPIO14 | check `setlock`; servo must be on GPIO13 |
| Finger will not relock | lock angle short of the teeth | raise `setlock` a few degrees |
| Line tangles on the spool | line exits the wrong side, or slack on rewind | re-wind per 05 step 16; reduce `rpm` |
| Retriggers on people walking past or leaving | LD2450 window too wide, or running the LD2410C fallback | narrow `doorwidth`, raise `approach`; check `sensor 2450` |
| ESP32 resets when servo moves | 5 V dips | fit the 470 uF capacitor at the servo |
| Rewind stops early, fault "tripped far too early" | line snagged, or switch noise from the motor wires | clear the snag; route the switch lead away from the motor wires |
| Fault "ran without the limit switch tripping" | bead misses the flap, flap stuck, or switch unplugged | check the flap swings freely and the roller touches its tail (doc 09 step 4); check `status` shows the switch changing when the flap is lifted |
| Fault "still pressed after a drop" | switch reads backwards | `liminv` the other way, `save` |
| `jog` refused, "limit switch is pressed" | spider already home, or switch reads backwards | check 3b |
| Page will not load | board not on the network | USB console `wifi`; if it made its own network, join DropSpider-setup and use 192.168.4.1 |
| USB upload stops at "Connecting" | board not entering flash mode | hold BOOT, tap EN, let go of BOOT, upload again |

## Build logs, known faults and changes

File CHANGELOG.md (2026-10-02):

# Changelog

Finished work, newest first, one plain line each. Shape from Keep a Changelog (keepachangelog.com). Work still to do is in `ROADMAP.md`; the full detail of any line is in the git history for that date.

## 2026-10-01

### Changed
- Firmware: the motor never turns with the finger in (owner rule). `jog` and `rewind` run the release first (finger out with the 1/12 turn unload) unless the finger is already out; the lock's seat move is the one exception. Flashed by WiFi; `jog 400` logged the finger going out first, then the move; `jog -400` with the finger already out went straight to the move.
- Line anchor: a 1 mm hole drilled through the barrel skin into a spoke window, line tied round a 10 mm stub of 1.75 mm filament inside, CA on the knot (was an arbor knot with CA, which can turn on the smooth barrel). Doc 05 step 5 and the build guide.
- Owner keeps the current spool stack; the one-piece spool handoff is now for later, with the bearing hole 0.1 smaller (10.2) and a built-in line anchor hole. Open item V21: the slip only shows above the spider's weight, so the limit switch must be on before arming.
- Inverted install turned end for end to match the owner's build (photo): servo end at the beam, pad end away from it. Radar fork moves to the pad end, 2x M3 drilled at x -80, z 38.5 and 72.5; nothing blocks its view, its centre line passes under the beam (409 mm below the ceiling), the cradle clears every part from 20 to 90 degrees. Line now 54 mm from the beam's face (was 117). Model, drilling template, install picture, doc 05, doc 06 and build guide updated.
- Driver pins: DIR GPIO27, STEP GPIO26, EN GPIO25 (were STEP 25, DIR 26, EN 27), so D27, D26, D25 match the expansion board's DIR, STEP, EN columns and a 3-wire ribbon goes straight across (owner). Firmware built; not yet flashed (board not connected). Doc 02, wiring guide, wiring picture and build guide updated; expansion board wires go on the S row, ground to any G, V empty.

## 2026-09-30

### Changed
- `fairlead_flap_inv`: owner's redesign. The tab runs 3.7 mm further toward the hinge and a sloped web fills the notch beside the prong, so the side has no step for the line to catch; the line slot runs 1.4 mm deeper. Source (`cad/inverted.py`) now builds it to within 3.5 mm3 of his STL; his STL is kept as the print file. All inverted checks unchanged (clashes, line path, hard stop 14.75, roller push 4.13, rest 9.5).
- Doc 02: motor part number 11HS12-0674S, 5.6 ohm coil check, female jumper ends on the bare leads.

## 2026-09-29

### Added
- `bearing_retainer`: thin 2 mm plate on the end plate's outside face that stops a loose 606ZZ walking out; 12 mm hole for the rod, 2x M3 into pilots drilled through the end plate. No clashes in either install.
- Build note (owner's build): about 4 mm of shim on the motor side of the spool and 5 mm on the 606ZZ side for a snug, free stack.

### Changed
- Ratchet disk is now a plain 7 mm plate, teeth full height, flat both faces (owner: no lip); it prints with the shield face on the bed, so the counterbores need no bridging. 0.4 edge breaks on the bearing holes where they print on the bed. Assembly order: screw the three together first, then press the HF0612 through all three.
- Spool stack (owner): new `spool_shield`, a flat 1.5 mm disc 64 mm across between the ratchet disk and the spool body, so the line cannot reach the teeth. No boss and recess any more (it left a 1 mm gap at the rim): all three sit on flat faces, centred by the HF0612 running through all three 10.3 holes and the 3 screws. Ratchet gets a 1 mm flat plateau so the shield clears the finger by 1 mm; spool body shortened to keep the stack length, line channel now 3.5 mm. Finger seating, clashes and the inverted checks unchanged. `spool_ratchet`, `spool_shield`, `spool_body` exported.

## 2026-09-28

### Added
- Radar handoff: four things the firmware must handle in the inverted install (radar axes, the spider in the radar's view, aluminum, the longer line between spool and flap).
- `ROADMAP.md`, this changelog, and a doc map in the README: each file has one job.

### Changed
- HF0612 holes in `spool_body` and the `spool_ratchet` center both 10.3 (owner: same diameter in both; 10.0 would not go in, 10.2 tight, 10.7 loose). Both STLs re-exported. Was: `spool_body` 10.3 (owner: 10.0 would not go in, 10.2 tight, 10.7 loose). Only `spool_body.stl` re-exported.
- Spool body and ratchet disk spoked (3 spokes, 3 windows): 18.3 to 8.0 and 16.1 to 9.5 cm3, every mating face unchanged. Fairlead block rounded (column edges r 1.5, as the build123d trial) with 3 through-windows: 15.7 to 12.8 cm3, all inverted checks unchanged. Build guide pictures redrawn with both.
- Every clockwise and counterclockwise in the docs, the build guide, the pictures and the firmware comment is now seen from behind the motor (owner): spider falling counterclockwise, winding clockwise, the HF0612 locks when the rod turns clockwise. Mirror of the old 606ZZ-end wording; nothing on the parts changed.
- HF0612 one-way bearing holes opened (owner: 10.0 would not take it, the disk's 10.6 took the stub only after sanding): `spool_body` 10.7 tight press, `spool_ratchet` center hole 11.0 slip. Both STLs re-exported; reprint both.
- Build guide: the HF0612 labelled as the one-way bearing everywhere, drawn as its own part in the exploded view, and a new cut-away picture of every part on the rod; the title bar is plain text again.
- Build guide covers only the inverted install; the ceiling install stays in doc 06. Web page picture matched to the firmware; radar chip marked not live until task 2; finger angles 85 and 50.
- Build guide: no separate power board. The expansion board and the 5 V buck are hot-glued beside the main board; 12 V runs straight from the jack.
- Task 1 handoff cut down to the work still to do.

### Removed
- Wall-install drafts (hinge plate, hinge clip, tie bar, strut, braced shelf) to `cad/retired/` and `docs/retired/`.
- Inverted-install handoff to `docs/retired/`: design, checks, docs and the Fable check all done; building it is on the roadmap.

## 2026-09-27

### Added
- Firmware Rev C.1: motor-led drop, release under load (wind 1/12 turn while the finger swings out), seat move on lock, home remembered from the last cycle, settings `dropmm`, `droprpm`, `dropacc`, `dropdec`, `relms`. Flashed over WiFi.
- Inverted install (owner's plan, approved): device turned over on two 6 in steel corner braces on the beam's inside face, line out through the base. `cad/inverted.py`, `fairlead_base.stl`, the drilling template `bracket_footprint_inverted.svg`, doc 06 section, open item V18. CAD-checked, not built.
- Radar fork bolted with 2x M3 (`ld2450_fork_screw.stl`), no glue; ears 4 mm thick, 12 mm across.

### Changed
- 606ZZ bearing seat drawn at 17.0 mm (16.8 would not take the bearing even heated).
- Flap: the prong beside the line slot widened from 1.2 to 3.8 mm.
- Rule: after a CAD change, export and check only the part that changed; no full rebuilds.

### Fixed
- Inverted install, from the Fable check: brace bolt zones, lead routing, a boss under the short block screw, 7 mm line hole.

### Logged
- Servo is a positioning MG90, not a 360 one; finger angles set to 85 (lock) and 50 (release).

## 2026-09-26

### Changed
- Line is 6 lb nylon monofilament, no elastic, no braid.
- Finger presses straight onto the servo spline, no horn; socket drawn 5.0 mm.
- Fairlead: no glue, 2x countersunk M3; one flat mounting face; body reinforced; flap hinge pin is an M2 bolt.
- Radar on the device in a cradle that tilts on one M3 bolt; porch measured (8 ft ceiling, 10 in beam, device 12 in behind it), tilt 50 degrees.
- Fit-check fixes on every part (holes print small on the owner's printer).

### Fixed
- The fairlead bore was never cut; the part printed solid.

### Added
- Laser-cutter drawing of the bracket's ceiling face with every hole.

## 2026-09-25

### Added
- Build guide: one page for wiring, assembly, power-up and web setup; protoboard layout.
- `scripts/update_firmware.bat`: double-click update by WiFi or USB. `tools/esptool_noreset.py` for USB flashing.
- Rev C.1 owner design and docs: clutch direction fix (M1), finger release fix (M2), LD2450, fairlead with KW12-3 switch.

### Changed
- Board in use is the 30-pin ESP32 DevKit V1. 5 V supply is a fixed-5 V MP1584EN buck.

### Logged
- Board identified by esptool, first USB flash, joined the home WiFi, network updates work.

## 2026-09-24

### Added
- Firmware: web page (console, bench controls, settings, network setup), network firmware updates, limit switch hard cut-off, three-strike fault stop. The machine runs on its own task, so a rewind no longer blocks the console.
- `tools/console.py`: console commands over USB or the network.
- Standard PlatformIO layout, pinned platform, passwords kept out of git.
- Rev C handoff baseline.

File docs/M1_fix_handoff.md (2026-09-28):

# M1 fix handoff: mechanical owner to software/electrical team

Date: 2026-09-24. Revision: Rev C.1 (no reprints, no new hardware).

## Verdict

**M1 is confirmed and was a design error on the mechanical side.** A one-way clutch only lets the spool overrun the rod in the same direction the rod can drive it. As drawn in Rev C, the motor could never wind the spool up. The team's reading of doc 01 was correct.

**Fix: flip the HF0612 and make the drop motor-led.** The motor spins out ahead in the unwind direction under power, and the spool runs down behind it on the clutch. Same parts, firmware change only. Docs 01, 05, 07, 08 and `CLAUDE.md` are already updated by the mechanical owner. Firmware and doc 04 are yours.

## Why the other fixes were rejected

| Option | Why not |
|---|---|
| Let the spider back-drive the unpowered motor (clutch flipped, driver off) | Owner tested: the stepper's unpowered drag is too high for a clean fall |
| Relay to open the motor coils during the drop | Owner rule for Rev C.1: existing hardware only |
| Servo-actuated dog clutch or tilt-spool | New mechanism and reprints; that is Mechanism B (`dropspider-tiltspool`), not a fix |

## How the clutch works now

All directions seen from behind the motor (standing behind the stepper motor, looking along the rod toward the spool). Spider falling = spool turns counterclockwise (CCW). Winding up = clockwise (CW).

| Situation | Spool vs rod | Clutch | Result |
|---|---|---|---|
| Rod held, spool turned CCW by hand | spool CCW relative | **locks** | assembly check |
| Rod held, spool turned CW by hand | spool CW relative | free | assembly check |
| Rewind: motor turns rod CW, spider weight holds spool back | spool CCW relative | **locks** | motor winds the spool up |
| Drop: motor turns rod CCW faster than the spool falls | spool CW relative | free | spool falls at gravity, lagging the rod |
| Drop: spool catches up to the rod's speed | spool CCW relative | **locks** | fall speed capped at the motor's speed |
| Lock seat: motor turns rod CCW after a tooth lands on the finger | spool CW relative | free | motor runs on harmlessly, spool stays on the tooth |

The spool can never travel faster than the motor. So the motor sets the top speed and the stopping point of every drop, and the knot never slams. The line's stretch (6 lb mono) is the backstop in case the motor loses its grip.

## Second finding: M2, the finger cannot release under load

Found while reworking the sequence, not yet tested. With the spider hanging, the tooth presses the finger up onto the ledge. The release swing moves the finger tip toward the floor, straight into the same tooth's steep face. As drawn, the servo would be fighting the tooth.

Fix: wind the spool CW about 1/12 turn **while** the servo swings out. In that direction the finger rides up the tooth's ramp and out, the same way a ratchet clicks. The motor is already powered for the drop, so this costs about 100 ms.

## Firmware spec (yours to implement in `src/machine.cpp`, settings, console, web)

Directions below use the firmware's own convention: + = rewind (CW), - = unwind (CCW).

**Drop sequence (replaces `startCycle` / `ST_RELEASE`):**
1. `driverOn()`.
2. At the same moment: `servoWrite(S.servoRel)` and start an unload move of `+UNLOAD_STEPS` (default `STEPS_PER_TURN / 12`) at a slow speed (default 120 rpm).
3. Wait `S.releaseMs` from the servo command (default 250 ms; finger clear of the teeth).
4. Drop move: `-dropSteps()` at `S.dropRpm`, acceleration `S.dropAcc`, deceleration `S.dropDec`.
5. Driver stays on: the motor holds the spider at the bottom through the clutch. Then `ST_SETTLE` as today.

`dropSteps()` = `(S.dropMm + unload distance) / (PI * BARREL_DIA_MM) * STEPS_PER_TURN`. Refuse any `dropMm` that would reach within 30 mm of the knot: `dropMm <= lineMm - SPOOL_TO_EYELET_MM - 30`.

**Rewind:** unchanged. Limit switch and bead stop work as before.

**Lock sequence (replaces `ST_LOCK_IN` / `ST_LOCK_SEAT`):**
1. Motor on and holding (end of rewind). `servoWrite(S.servoLock)`, wait `SERVO_MOVE_MS`. The finger may land on a tooth tip; that is fine.
2. Seat move: `-SEAT_STEPS` (default `STEPS_PER_TURN / 12 * 1.2`) at `SEAT_RPM` (default 30). The spool follows down until a tooth lands on the finger; after that the clutch slips and the motor runs on alone.
3. `driverOff()`, then `servoOff()` after `LOCK_SEAT_MS`.

**Bench commands:** `rel` must now use the drop sequence steps 1 to 3 (unload + release) with the driver on, then stop; a bare servo release with the driver off will jam per M2. Add `dropnow` or reuse `drop` for the full powered drop.

**New settings** (NVS, console, web page, all with range checks):

| Setting | Console | Default | Range | Meaning |
|---|---|---|---|---|
| dropMm | `dropmm` | lineMm - 40 - 60 | 100 to lineMm - 70 | how far the spider travels |
| dropRpm | `droprpm` | 500 | 100 to 900 | top speed of the drop |
| dropAcc | `dropacc` | 120000 | 20000 to 400000 | microsteps/s squared. 100000 is about 1 g at the barrel |
| dropDec | `dropdec` | 60000 | 10000 to 200000 | about 0.6 g. Must stay low: see torque note |
| releaseMs | `relms` | 250 | 100 to 600 | finger travel time before the drop starts |

Unit check for the team: one microstep = pi x 50 mm / 1600 = 0.098 mm of line. 1 m/s is about 610 rpm.

**Torque note:** stopping the spider takes motor torque on top of holding its weight. At 0.6 A and 500 rpm this motor has roughly 2.5 to 3 Ncm (estimate, not measured). That stops a spider of 60 g or less at about 0.6 g. A 100 g spider needs `dropDec` near 20000 and a longer stop. If the motor loses steps during the stop, the spool runs free and the line's stretch catches it: a scare, not a failure. Log it as a fault only if it repeats.

**FastAccelStepper:** check whether it supports a separate deceleration within one move. If not, the known pattern is to change acceleration part-way through the move (`setAcceleration` + `applySpeedAcceleration`) at the point where the gentler stop needs to begin. Name the approach you use and why.

**Limit switch interplay:** the seat move lets the bead drop up to about 13 mm below the switch. Check that `limitHome()` still reads pressed after a seat (depends on lever travel). If it does not, the boot check and the "spider not home" message need a tolerance, not a code path that rewinds.

**Unchanged:** boot never rewinds; armed idle = driver off and servo detached; servo on GPIO13.

## Bench tests (add to `commissioning_log.md` as T1 to T8)

| # | Test | Pass |
|---|---|---|
| T1 | Clutch direction by hand, per the table above | Rod held: spool locks CCW, free CW |
| T2 | `rewind` from the bottom | Spool winds up, limit switch stops it |
| T3 | Release under load (M2), 10 times | Finger clears every time, no servo buzz, spider starts falling |
| T4 | Full `drop`, 5 times at 500 rpm; phone slow-motion video of the drop | 0.7 m in 0.7 s or less; no lost steps logged |
| T5 | Stop height, 10 drops | Spider stops within 20 mm of the same height each time; no bounce off the line's end |
| T6 | Lock seat, 10 times | Finger seats every time; spider drops no more than 13 mm; limit reading as expected |
| T7 | Raise `droprpm` in steps of 100 until steps are lost | Record the highest clean speed with the real spider; set 100 below it |
| T8 | 20 full cycles | Motor warm, not hot; no ESP32 resets; coupler screws tight |

## Doc status

| Doc | Status |
|---|---|
| 01 mechanical design | updated by mechanical owner |
| 05 assembly (B2, B4, 11) | updated |
| 07 commissioning (7, 8, 10, troubleshooting) | updated |
| 08 open items (M1, M2, V13, V14) | updated |
| CLAUDE.md hard constraints | updated |
| 04 firmware, web page help text | **yours**, after the firmware lands |

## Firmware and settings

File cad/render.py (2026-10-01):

"""Renders assembly images into ../docs/img. Run after generate.py: python render.py"""
import os, math, numpy as np, trimesh, matplotlib
matplotlib.use("Agg")
import matplotlib.pyplot as plt
import generate as G
import raster

IMG = os.path.join(G.HERE, "..", "docs", "img"); os.makedirs(IMG, exist_ok=True)
COL = {"bracket": "#9aa0a6", "spool_ratchet": "#1f6feb", "spool_body": "#58a6ff",
       "fairlead_body": "#8b5cf6", "fairlead_flap": "#d946ef", "fairlead_flap_inv": "#d946ef", "switch_kw12": "#111111",
       "finger": "#e5534b", "rod_6mm": "#444", "coupler": "#d4a72c", "spacer_A": "#2da44e", "spacer_B": "#2da44e",
       "bearing_606": "#57606a", "hf0612": "#f59e0b", "bearing_retainer": "#6b7280", "spool_shield": "#a5b4fc", "motor_nema11": "#24292f", "servo_sg90": "#0969da",
       "ld2450_fork": "#ea580c", "ld2450_cradle": "#f97316", "ld2450_radar": "#1d4f38",
       "wall_mount": "#b45309", "ld2450_fork_screw": "#ea580c", "beam": "#c9a66b", "ceiling": "#e5e7eb",
       "bolt": "#57606a", "nut": "#374151", "screw": "#8a6d3b",
       "hinge_plate": "#b45309", "hinge_clip": "#d97706", "pin": "#57606a", "tie_bar": "#92400e", "strut": "#f59e0b",
       "fairlead_base": "#8b5cf6", "brace": "#6b7280", "line": "#111111", "bead": "#f59e0b", "electronics": "#16a34a"}
LABEL = {"bracket": "bracket.stl", "spool_ratchet": "spool_ratchet.stl", "spool_body": "spool_body.stl (the HF0612 presses into it)",
         "fairlead_body": "fairlead_body.stl", "fairlead_flap": "fairlead_flap.stl (hinged bumper)", "fairlead_flap_inv": "fairlead_flap_inv.stl (flap with the tab under the switch)",
         "switch_kw12": "KW12-3 limit switch", "finger": "finger.stl on the SG90 spline", "rod_6mm": "6 mm rod, 100 mm",
         "coupler": "5-to-6 mm coupler", "spacer_A": "spacer_A_6mm.stl", "spacer_B": "spacer_B_50mm.stl",
         "bearing_606": "606ZZ ball bearing", "hf0612": "HF0612 one-way bearing (clutch), pressed into spool_body", "bearing_retainer": "bearing_retainer.stl (holds the 606ZZ in, 2x M3)", "spool_shield": "spool_shield.stl (flat disc between disk and spool)", "motor_nema11": "NEMA 11 motor", "servo_sg90": "SG90 servo",
         "ld2450_fork": "ld2450_fork.stl (glued)", "ld2450_cradle": "ld2450_cradle.stl (tilts on one M3 bolt)", "ld2450_radar": "LD2450 radar",
         "wall_mount": "wall_mount.stl (shelf, wall plate, 2 braces)", "ld2450_fork_screw": "ld2450_fork_screw.stl (2x M3 through the base, no glue)",
         "beam": "porch beam (stand-in)", "ceiling": "porch ceiling (stand-in)",
         "bolt": "6x M3 x 10 to 12 bolt, from below", "nut": "6x M3 nut, tapped into the shelf's pockets", "screw": "4x #4 x 1 in wood screw",
         "hinge_plate": "hinge_plate.stl (4x #4 screws into the beam)", "hinge_clip": "hinge_clip.stl x2 (2x M3 each, on the pad)",
         "pin": "pins: 2x M3 x 25 (hinge), 4x M3 x 20 (struts), nuts", "tie_bar": "tie_bar.stl (2x M3 through the base's x 65 holes)",
         "strut": "strut.stl x2 (the 45 degree bar, pushed)",
         "fairlead_base": "fairlead_base.stl (under the base, 2x M3 from inside)", "brace": "2x steel corner brace, 6 in (owner drills the base)",
         "line": "6 lb line, out through a 7 mm hole in the base", "bead": "stop bead",
         "electronics": "room for the controller board on the pad, 52 x 75 x 30 (stand-in box)"}

def rview(m):
    # render world: X = x, Y = z (rod), Z = -y (floor is down, ceiling mount on top)
    mm = m.copy(); v = mm.vertices.copy(); mm.vertices = np.column_stack([v[:, 0], v[:, 2], -v[:, 1]]); return mm

def save(img, name, title, labels=(), keys=(), loc="upper right"):
    import matplotlib.patches as mp
    fig, ax = plt.subplots(figsize=(img.shape[1] / 100, img.shape[0] / 100 + 0.5))
    ax.imshow(img); ax.set_axis_off(); ax.set_title(title, fontsize=13)
    for lab in labels:
        x, y, t = lab[:3]
        if len(lab) == 5: ax.annotate(t, xy=lab[3:], xytext=(x, y), fontsize=10, bbox=dict(fc="white", ec="0.6", alpha=0.9), arrowprops=dict(arrowstyle="->", color="0.3"))   # label with a pointer to the part
        else: ax.text(x, y, t, fontsize=10, bbox=dict(fc="white", ec="0.6", alpha=0.9))
    if keys:
        ax.legend(handles=[mp.Patch(color=COL[k], label=LABEL[k]) for k in keys], loc=loc, fontsize=10, framealpha=0.95)
    fig.savefig(os.path.join(IMG, name), dpi=100, bbox_inches="tight"); plt.close(fig)

def lbl(proj, pt, dx, dy, text, arrow=False):
    x, y, _ = proj(np.array([pt])); return (x[0] + dx, y[0] + dy, text) + ((x[0], y[0]) if arrow else ())

def assembly_png():
    A = G.assembly()
    for view, (el, az) in {"assembly_iso.png": (-28, -55), "assembly_iso_top.png": (30, -125)}.items():
        img, proj = raster.render([(rview(m), COL[k]) for k, m in A.items()], elev=el, azim=az, W=1300, H=950)
        labels = [lbl(proj, (-25, 45, -76), 15, 25, "line exits down through the fairlead")] if view == "assembly_iso.png" else []
        save(img, view, "Mechanism A, Rev C.1 - installed, ceiling mount" + (" (view from below)" if view == "assembly_iso.png" else " (view from above, ceiling removed)"), labels, keys=list(A.keys()))

def exploded_png():
    A = G.assembly()
    # (dx, dy, dz) in assembly frame; +dy moves toward the floor
    off = {"bracket": (0, 0, 0), "servo_sg90": (0, 0, 0), "finger": (0, 0, 22),
           "motor_nema11": (0, 90, -95), "coupler": (0, 90, -45), "spacer_A": (0, 90, -8),
           "spool_ratchet": (0, 90, 20), "hf0612": (0, 90, 38), "spool_shield": (0, 90, 46), "spool_body": (0, 90, 55), "spacer_B": (0, 90, 95),
           "bearing_606": (0, 90, 150), "rod_6mm": (0, 150, 20),
           "fairlead_body": (-110, 40, -40), "fairlead_flap": (-110, 40, -40), "switch_kw12": (-110, 40, -40),
           "ld2450_fork": (40, 20, 20), "ld2450_cradle": (70, 60, 20), "ld2450_radar": (100, 75, 20)}
    items = []
    for k, m in A.items():
        mm = m.copy(); mm.apply_translation(off.get(k, (0, 0, 0))); items.append((rview(mm), COL[k]))
    img, proj = raster.render(items, elev=-12, azim=-30, W=1600, H=1050)
    labels = [lbl(proj, (0, 82, -(G.AXIS_Y + 90) - 5), 170, 120, "HF0612 one-way bearing (the clutch):\npresses into spool_body", True)]
    save(img, "exploded.png", "Exploded view. Rod order from motor: coupler, spacer A, ratchet disk, HF0612 one-way bearing in spool body, spacer B, 606ZZ", labels, keys=list(A.keys()))

def lock_png():
    fig, ax = plt.subplots(figsize=(10, 8))
    P = G.ratchet_poly(); xs, ys = P.exterior.xy
    ax.fill(np.array(xs), np.array(ys) + G.AXIS_Y, color="#1f6feb", alpha=0.25); ax.plot(np.array(xs), np.array(ys) + G.AXIS_Y, "#1f6feb")
    for w in G.spoke_window_polys(4.6):                                         # the disk's three through-windows (spoked, owner 2026-09-28)
        wx, wy = w.exterior.xy; ax.fill(np.array(wx), np.array(wy) + G.AXIS_Y, color="white", ec="#1f6feb", lw=1)
    ax.add_patch(plt.Circle((0, G.AXIS_Y), 25, fill=False, ls="--", color="#58a6ff"))
    ax.add_patch(plt.Circle((0, G.AXIS_Y), 3, color="#444"))
    ax.add_patch(plt.Rectangle((G.SERVO_SHAFT_X - 20.5, G.AXIS_Y - 3), 23.5, 6, color="#e5534b"))
    ax.add_patch(plt.Circle((G.SERVO_SHAFT_X, G.AXIS_Y), 5, color="#e5534b"))
    a = math.radians(60)
    tipx, tipy = G.SERVO_SHAFT_X - 20.5 * math.cos(a), G.AXIS_Y + 20.5 * math.sin(a)
    ax.plot([G.SERVO_SHAFT_X, tipx], [G.AXIS_Y, tipy], color="#e5534b", lw=6, alpha=0.3)
    ax.text(tipx - 4, tipy + 3, "RELEASED (servo 30)", color="#e5534b", fontsize=9)
    ax.text(45.5, G.AXIS_Y - 9, "LOCKED (servo 90)", color="#e5534b", fontsize=9)
    ax.add_patch(plt.Rectangle((36, 4), 8, 32, color="#9aa0a6"))
    ax.text(45, 10, "ledge: takes the\nlocking load", fontsize=9)
    ax.add_patch(plt.Rectangle((-90, 0), 170, 4, color="#9aa0a6")); ax.text(-88, -7, "base, y = 0 (ceiling)", fontsize=9)
    ax.add_patch(plt.Rectangle((43.8, 33.6), 23.4, 12.8, fill=False, ec="#0969da", lw=2)); ax.text(60, 48, "SG90", color="#0969da")
    ax.add_patch(plt.Rectangle((-36, 70), 17, 8, color="#8b5cf6")); ax.text(-70, 82, "fairlead (see doc 09)", color="#8b5cf6")
    ax.plot([-25, -25], [40, 115], color="k", lw=1.5); ax.text(-23, 105, "line to spider", fontsize=9)
    ax.annotate("", xy=(20, 65), xytext=(-20, 67), arrowprops=dict(arrowstyle="->", lw=2.5, color="green",
                connectionstyle="arc3,rad=-0.3"))
    ax.text(14, 78, "UNWIND (spider falling):\ncounterclockwise in this view", color="green", fontsize=10, ha="center", bbox=dict(fc="white", ec="none", alpha=0.85, pad=1.5))
    ax.annotate("tooth pushes finger\nUP onto the ledge", xy=(31, 37), xytext=(5, 12), fontsize=9,
                arrowprops=dict(arrowstyle="->"))
    ax.set_aspect("equal"); ax.invert_yaxis(); ax.set_xlim(-95, 85); ax.set_ylim(118, -12)
    ax.set_title("Lock detail: section through the ratchet disk, seen from behind the motor, ceiling install\n(every direction in the docs is seen from this side)")
    ax.grid(alpha=0.2)
    fig.savefig(os.path.join(IMG, "lock_detail.png"), dpi=120, bbox_inches="tight"); plt.close(fig)

def base_png():
    import fairlead as F
    b = G.bracket(); s = b.section(plane_origin=[0, 1.5, 0], plane_normal=[0, 1, 0])
    fig, ax = plt.subplots(figsize=(11, 6.5))
    for d in s.discrete: ax.plot(d[:, 0], d[:, 2], "k")
    sg = F.fairlead_body().section(plane_origin=[0, 5, 0], plane_normal=[0, 1, 0])
    for d in sg.discrete: ax.fill(d[:, 0], d[:, 2], color="#8b5cf6", alpha=0.4)
    ax.add_patch(plt.Rectangle((-88, 18), 52, 75, fill=False, ls="--", ec="#2da44e"))
    ax.text(-86, 95, "electronics area 52 x 75 (board may overhang -x edge)", color="#2da44e", fontsize=9)
    for x, z in [(-80, 28), (-56, 28), (-80, 83), (-56, 83)]: ax.text(x + 2, z + 2, "PCB", fontsize=7, color="#2da44e")
    for z in (28, 83): ax.text(-31, z + 2, "fairlead", fontsize=7, color="#8b5cf6")
    for z in (20, 90): ax.text(67, z + 2, "mount", fontsize=7)
    ax.text(-10, 60, "window", fontsize=8)
    ax.set_aspect("equal"); ax.set_xlabel("x (mm)"); ax.set_ylabel("z (mm, along rod)")
    ax.set_title("Base, viewed from the room side (y=0 plane). Motor end at z=0, 606ZZ end at z=110")
    fig.savefig(os.path.join(IMG, "base_layout.png"), dpi=120, bbox_inches="tight"); plt.close(fig)

def steps_png():
    import matplotlib.colors as mc
    A = G.assembly()
    base = ["bracket"]
    fl = ("fairlead_body", "fairlead_flap", "switch_kw12")
    rd = ("ld2450_fork", "ld2450_cradle", "ld2450_radar")
    steps = [("Step 1: press 606ZZ into the end plate, motor onto the motor plate", base, ["bearing_606", "motor_nema11"]),
             ("Step 2: coupler onto the motor shaft (set screw on the 5 mm side)", base + ["bearing_606", "motor_nema11"], ["coupler"]),
             ("Step 3: hold spacer A, spool, spacer B in the gap, disk toward the motor", base + ["bearing_606", "motor_nema11", "coupler"], ["spacer_A", "spool_ratchet", "hf0612", "spool_shield", "spool_body", "spacer_B"]),
             ("Step 4: push the rod in from the 606ZZ end, through everything, into the coupler", base + ["bearing_606", "motor_nema11", "coupler", "spacer_A", "spool_ratchet", "hf0612", "spool_shield", "spool_body", "spacer_B"], ["rod_6mm"]),
             ("Step 5: SG90 into the tower, finger pressed onto its spline", [k for k in A if k not in ("servo_sg90", "finger") + fl + rd], ["servo_sg90", "finger"]),
             ("Step 6: fairlead with flap and limit switch, glued to the pad", [k for k in A if k not in fl + rd], list(fl)),
             ("Step 7: radar fork glued under the servo end, cradle on one M3 bolt, radar slid in", [k for k in A if k not in rd], list(rd))]
    for i, (title, old, new) in enumerate(steps, 1):
        items = [(rview(A[k]), tuple(0.55 + 0.45 * np.array(mc.to_rgb(COL[k])))) for k in old]
        items += [(rview(A[k]), COL[k]) for k in new]
        img, proj = raster.render(items, elev=-25, azim=-50, W=1000, H=720)
        save(img, f"step{i}.png", title + "   (new parts in full color)", (), keys=new)

def fairlead_png():
    import fairlead as F, matplotlib.colors as mc
    A = G.assembly()
    ghost = lambda k: tuple(0.6 + 0.4 * np.array(mc.to_rgb(COL[k])))
    bead = trimesh.creation.icosphere(radius=4, subdivisions=3)
    line = G.vcyl(0.3, 70, 40, F.LX, F.LZ)
    for name, deg, title in [("fairlead_rest.png", 0, "Fairlead + limit switch, spider away: flap resting, switch open"),
                             ("fairlead_home.png", -14.5, "Spider home: bead lifts the flap, tail presses the roller, flap hits the hard stop")]:
        flap = F.rotate_flap(A["fairlead_flap"], deg)
        b = bead.copy(); b.apply_translation([F.LX, F.HY + F.FT / 2 + 4 + (12 if deg == 0 else -3.3), F.LZ])
        items = [(rview(A[k]), ghost(k)) for k in ("bracket", "spool_ratchet", "spool_body")]
        items += [(rview(A["fairlead_body"]), COL["fairlead_body"]), (rview(flap), COL["fairlead_flap"]),
                  (rview(A["switch_kw12"]), COL["switch_kw12"]), (rview(b), "#f59e0b"), (rview(line), "#222222")]
        img, proj = raster.render(items, elev=-8, azim=-8, W=1200, H=900)
        save(img, name, title, (), keys=["fairlead_body", "fairlead_flap", "switch_kw12"])

def fairlead_exploded_png():
    """Fairlead sub-assembly: body, flap, M2 hinge bolt, KW12-3, 2x M2 screws, exploded along the pin axis (x)."""
    import fairlead as F
    import matplotlib.patches as mp
    body, flap, sw = F.fairlead_body(), F.fairlead_flap(), F.switch_model()
    pin = F.xcyl(0.875, -36, -6, F.PY, F.HZ); pin.apply_translation([-40, 0, 0])
    fl = flap.copy(); fl.apply_translation([25, 22, 0])
    s2 = sw.copy(); s2.apply_translation([45, 30, 0])
    screws = []
    for z in F.SW_HOLES_Z:
        sc = F.xcyl(1.0, -40, -28, F.SW_HOLE_Y, z); sc.apply_translation([-25, 0, 0]); screws.append(sc)
    items = [(rview(body), COL["fairlead_body"]), (rview(fl), COL["fairlead_flap"]), (rview(s2), COL["switch_kw12"]),
             (rview(pin), "#f59e0b")] + [(rview(sc), "#57606a") for sc in screws]
    img, proj = raster.render(items, elev=12, azim=215, W=1300, H=900)
    fig, ax = plt.subplots(figsize=(13, 9.6)); ax.imshow(img); ax.set_axis_off()
    ax.set_title("Fairlead sub-assembly (1 body, 1 flap): M2 hinge bolt in from the flap side, threads into the body,\nswitch on the plate's far side with 2x M2 through the slots, roller end toward the fairlead", fontsize=12)
    ax.legend(handles=[mp.Patch(color=COL["fairlead_body"], label="fairlead_body.stl (x1)"),
                       mp.Patch(color=COL["fairlead_flap"], label="fairlead_flap.stl (x1)"),
                       mp.Patch(color="#f59e0b", label="hinge pin: M2 bolt, 16 to 20 mm"),
                       mp.Patch(color=COL["switch_kw12"], label="KW12-3 roller switch"),
                       mp.Patch(color="#57606a", label="2x M2 x 12 screw + nut")], loc="lower left", fontsize=10)
    fig.savefig(os.path.join(IMG, "fairlead_exploded.png"), dpi=100, bbox_inches="tight"); plt.close(fig)

def inverted_png():
    """The owner's inverted install: device turned over on two 6 in corner braces standing up the beam, line out through the base."""
    import inverted as INV
    A = INV.assembly_inverted(); A.update(INV.line_and_bead())
    A.update({k: G.I(m, G.bx(-200, 250, -300, 200, -25, 135)) for k, m in INV.porch().items()})   # a short length of beam and ceiling, so the device reads
    key = lambda k: "brace" if k.startswith("brace") else k
    img, proj = raster.render([(INV.view_inv(m), COL[key(k)]) for k, m in A.items()], elev=-12, azim=210, W=1300, H=1000)   # from the pad end, beam behind (owner's build 2026-10-01: servo end at the beam)
    labels = [lbl(proj, (INV.LINE_X, -INV.LINE_Z, -110), 12, -60, f"line falls {abs(INV.LINE_X - INV.X_BEAM):.0f} mm from the beam's face", True),
              lbl(proj, (INV.X_BEAM - 140, -INV.BRACE_Z[0], -2), -260, 60, "base sits on the braces' flat legs", True),
              lbl(proj, (INV.LINE_X + 10, -INV.LINE_Z, -30), 200, 60, "fairlead, flap and switch under the base", True),
              lbl(proj, (INV.RADAR_FORK[0] - 25, -INV.RADAR_FORK[1], -40), -120, 120, "radar under the pad end, looking toward the beam and down", True)]
    save(img, "inverted_install.png", "Inverted install (owner's build, servo end at the beam): device turned over, sitting on two 6 in steel corner braces that stand up the beam, line out the bottom (view from below, inside the porch)",
         labels, keys=["bracket", "electronics", "fairlead_base", "fairlead_flap", "switch_kw12", "brace", "line", "bead", "ld2450_fork_screw", "ld2450_cradle", "ld2450_radar", "beam", "ceiling"], loc="upper right")

def inverted_fairlead_png(elev=-12, azim=35, name="inverted_fairlead.png"):
    """Close-up for the build guide: the fairlead block under the base, flap, switch, both block screws, line and bead."""
    import inverted as INV
    A = INV.assembly_inverted(); L = INV.line_and_bead(drop=45)
    base = G.I(A["bracket"], G.bx(0, 55, -60, 12, 10, 105))                  # just the base around the block
    screws = [G.U(G.vcyl(1.5, 12, -8.0, x, z), G.vcyl(2.75, 2.0, 4.0, x, z)) for x, z in INV.BLOCK_SCREWS]   # M3 x 12 from inside the base
    items = [(INV.view_inv(base), "#d0d3d6")]
    items += [(INV.view_inv(A[k]), COL[k]) for k in ("fairlead_base", "fairlead_flap", "switch_kw12")]
    items += [(INV.view_inv(m), "#57606a") for m in screws] + [(INV.view_inv(L["line"]), "#111111"), (INV.view_inv(L["bead"]), COL["bead"])]
    img, proj = raster.render(items, elev=elev, azim=azim, W=1300, H=1000)
    labels = [lbl(proj, (INV.LINE_X, -INV.LINE_Z, 25), 60, -40, "line: from the spool, down through the 7 mm hole, the block's bore, the flap's slot", True),
              lbl(proj, (INV.LINE_X, -INV.LINE_Z, -40), -420, -60, "bead: lifts the flap at home", True),
              lbl(proj, (43, -47, -15), 60, 20, "KW12-3 on the outer face, legs up; roller on the flap's tab", True),
              lbl(proj, (32, -83, -8), 80, -60, "M3 x 12 from inside the base (x2)", True)]
    save(img, name, "Inverted install, fairlead v2: switch above the flap, legs up, flap lowest (only the base is drawn above it)",
         labels, keys=["fairlead_base", "fairlead_flap_inv", "switch_kw12", "bead"], loc="lower left")

def rod_section_png(elev=8, azim=12):
    """Every part on the rod cut in half along the rod, so the HF0612 one-way bearing inside the spool shows (owner 2026-09-28)."""
    A = G.assembly()
    keys = ["bracket", "motor_nema11", "coupler", "rod_6mm", "spacer_A", "spool_ratchet", "hf0612", "spool_shield", "spool_body", "spacer_B", "bearing_606"]
    items = []
    for k in keys:
        m = A[k]
        if k == "bracket": m = G.I(m, G.bx(-40, 40, 12, 80, -5, 110))
        if k == "coupler": m = G.D(m, A["rod_6mm"], G.cyl(2.5, 20, 0, 0, G.AXIS_Y))
        cut = trimesh.intersections.slice_mesh_plane(m, plane_normal=[-1, 0, 0], plane_origin=[0, 0, 0], cap=True)
        items.append((rview(cut), "#d6d9dc" if k == "bracket" else COL[k]))
    img, proj = raster.render(items, elev=elev, azim=azim, W=1700, H=900)
    Y = G.AXIS_Y
    P = lambda y, z: (0, z, -y)
    labels = [lbl(proj, P(Y + 10, -16), -40, 150, "NEMA 11 motor", True),
              lbl(proj, P(Y + 5.5, 22), -60, 190, "5-to-6 mm coupler", True),
              lbl(proj, P(Y + 4.5, 33), -20, 230, "spacer A", True),
              lbl(proj, P(Y + 28, 39), -40, 120, "ratchet disk (spool_ratchet)", True),
              lbl(proj, P(Y - 4, 44), 40, -330, "HF0612 ONE-WAY BEARING (the clutch)\npressed into spool_body, flush with its flange,\nruns through the shield into the ratchet disk", True),
              lbl(proj, P(Y + 20, 48), 60, 110, "spool_body (line winds on the 50 mm barrel)", True),
              lbl(proj, P(Y + 30, 43.75), 150, 40, "spool_shield: flat disc, keeps the line off the teeth", True),
              lbl(proj, P(Y + 4.5, 75), 40, 170, "spacer B", True),
              lbl(proj, P(Y + 7, 103), 20, 120, "606ZZ ball bearing in the end plate", True),
              lbl(proj, P(Y, 112), -40, -120, "6 mm rod", True)]
    save(img, "rod_section.png", "Cut through the rod: every part on it, motor on the left, 606ZZ end on the right", labels)
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

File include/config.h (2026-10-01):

// DropSpider - Mechanism A (In-Line Single-Axle Clutch Spool) - Rev C
// Every pin and every fixed number, in one file. The values under DEFAULTS can be
// changed at runtime from the serial console or the web page and saved to flash.
#pragma once

// ---------- board ----------
// In use: 30-pin ESP32 DevKit V1 (ESP-WROOM-32, CP2102 USB). The 38-pin NodeMCU-32S
// also works unchanged. PlatformIO board: nodemcu-32s (same chip, same pins).
// Every pin below is on both the 30-pin and the 38-pin board, and none of them
// is a pin the chip uses for itself at boot except GPIO0 (the BOOT button) and
// GPIO2 (the LED), which are used for exactly those things.

// ---------- pins ----------
// D27, D26, D25 sit side by side on the header in the same order as the expansion board's DIR, STEP, EN
// columns, so a 3-wire ribbon goes across straight (owner 2026-10-01; was STEP 25, DIR 26, EN 27).
#define PIN_STEP        26   // -> expansion board STEP, S row
#define PIN_DIR         27   // -> expansion board DIR, S row
#define PIN_EN          25   // -> expansion board EN, S row   (LOW = driver on, HIGH = coils off)
#define PIN_SERVO       13   // -> SG90 orange. Not GPIO14: 14 pulses at boot and would twitch the finger.
#define PIN_SENSOR      33   // <- LD2410C OUT (HIGH = presence). Or AM312 PIR OUT.
#define PIN_LIMIT       32   // <- limit switch (3-pin endstop) at the eyelet: pressed = spider home
#define PIN_RADAR_RX    16   // <- LD2410C TX (reserved, not used by this firmware)
#define PIN_RADAR_TX    17   // -> LD2410C RX (reserved, not used by this firmware)
#define PIN_BUTTON      0    // on-board BOOT button: manual test drop (active LOW)
#define PIN_LED         2    // on-board blue LED

// ---------- mechanics (fixed by the printed parts) ----------
#define MOTOR_FULL_STEPS    200
#define MICROSTEPS          8      // expansion board DIP switches all OFF on a TMC2209 = 1/8
#define STEPS_PER_TURN      (MOTOR_FULL_STEPS * MICROSTEPS)
#define BARREL_DIA_MM       50.0f
#define SPOOL_TO_EYELET_MM  40.0f  // braid that stays between spool and eyelet when fully up
#define OVERSHOOT_TURNS     0.75f  // extra rewind so the bead always reaches the eyelet
#define RAMP_STEPS          600    // steps to reach full rewind speed from standstill

// ---------- Rev C.1 motor-led drop ----------
// + = rewind (clockwise seen from behind the motor), - = unwind (counterclockwise), as everywhere in the firmware.
#define UNLOAD_STEPS        (STEPS_PER_TURN / 12)          // wind up 1/12 turn while the finger swings out (M2)
#define UNLOAD_RPM          120
#define SEAT_STEPS          (STEPS_PER_TURN * 12 / 120)    // 1/12 turn x 1.2: lets the spool down onto a tooth
#define SEAT_RPM            30
#define DROP_KNOT_MARGIN_MM 30     // a drop never comes closer than this to the barrel knot
// The drop's gentler stop is switched in this far ahead of the exact point, so a
// late look by the machine task can never make the motor overshoot and reverse.
#define DECEL_MARGIN_S      0.010f
#define DECEL_MARGIN_STEPS  50
// Rewind ran this much more than the drop: the spool got ahead of the motor
// (lost steps on the stop) and the line's stretch caught the spider.
#define LOST_STEPS_WARN_MM  20

// ---------- timing ----------
#define SERVO_MOVE_MS       350    // time for the finger to travel
#define LOCK_SEAT_MS        700    // servo keeps pushing while the spool settles onto a tooth
#define TRIGGER_DEBOUNCE_MS 60     // sensor must stay HIGH this long
#define CLEAR_BEFORE_REARM  2000   // sensor must read LOW this long before the next scare
#define BUTTON_DEBOUNCE_MS  40
#define LIMIT_DEBOUNCE_MS   4      // short on purpose: this reading stops the motor
#define MACHINE_TICK_MS     2      // how often the machine task looks at everything
#define FAULT_STRIKES       3      // this many faults in a row and it stops arming itself

// ---------- limit switch sanity ----------
// If the switch trips before this fraction of the expected rewind, the line snagged
// or broke rather than the spider arriving.
#define REWIND_MIN_FRAC     0.25f

// ---------- network ----------
#define HOSTNAME            "dropspider"         // page at http://dropspider.local
#define AP_SSID             "DropSpider-setup"   // own network if the home one fails
#define AP_PASSWORD         "dropspider"         // 8 characters minimum
#define WIFI_JOIN_TIMEOUT_MS 15000
#define OTA_USER            "admin"              // web page update login; password is OTA_PASS

// Network credentials come from secrets.ini through platformio.ini. These
// fallbacks only exist so the file still compiles without them.
#ifndef WIFI_SSID
#define WIFI_SSID ""
#endif
#ifndef WIFI_PASS
#define WIFI_PASS ""
#endif
#ifndef OTA_PASS
#define OTA_PASS "dropspider"
#endif

#define CONSOLE_BAUD        115200
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

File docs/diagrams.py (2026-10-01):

"""Draws docs/img/wiring.png and docs/img/install.png. Run: python diagrams.py"""
import os, math, matplotlib
matplotlib.use("Agg")
import matplotlib.pyplot as plt
from matplotlib.patches import FancyBboxPatch, Rectangle, Circle, Polygon

IMG = os.path.join(os.path.dirname(os.path.abspath(__file__)), "img"); os.makedirs(IMG, exist_ok=True)

def pins_box(ax, x, y, w, title, left=(), right=(), color="#f6f8fa", step=0.55):
    n = max(len(left), len(right)); h = 0.5 + n * step
    ax.add_patch(FancyBboxPatch((x, y - h), w, h, boxstyle="round,pad=0.02,rounding_size=0.15", fc=color, ec="#24292f", lw=1.5))
    ax.text(x + w / 2, y + 0.12, title, ha="center", va="bottom", fontsize=11, weight="bold")
    pos = {}
    for i, p in enumerate(left):
        py = y - 0.5 - i * step; ax.plot(x, py, "o", color="#24292f", ms=4); ax.text(x + 0.12, py, p, va="center", fontsize=9.5); pos[p] = (x, py)
    for i, p in enumerate(right):
        py = y - 0.5 - i * step; ax.plot(x + w, py, "o", color="#24292f", ms=4); ax.text(x + w - 0.12, py, p, va="center", ha="right", fontsize=9.5); pos[p] = (x + w, py)
    return pos

def line(ax, a, b, color, label=None, mid=None, lw=2.4):
    (x0, y0), (x1, y1) = a, b
    if abs(y0 - y1) < 1e-6: ax.plot([x0, x1], [y0, y1], color=color, lw=lw)
    else:
        xm = mid if mid is not None else (x0 + x1) / 2
        ax.plot([x0, xm, xm, x1], [y0, y0, y1, y1], color=color, lw=lw)
    if label: ax.text((x0 + x1) / 2, y0 + 0.08, label, ha="center", va="bottom", fontsize=8.5, color=color)

RED, BLK, BLU, GRN, ORG, PUR, GRY = "#cf222e", "#24292f", "#0969da", "#1a7f37", "#bc4c00", "#8250df", "#6e7781"

def wiring():
    fig, (a1, a2) = plt.subplots(2, 1, figsize=(15, 15), gridspec_kw={"height_ratios": [1.05, 1]})
    for a in (a1, a2): a.set_xlim(0, 15); a.axis("off")
    a1.set_ylim(-1.4, 8.2); a2.set_ylim(-0.2, 7.0)
    a1.set_title("1. SIGNAL WIRING (thin jumper wires)", fontsize=14, weight="bold", loc="left")
    drv = pins_box(a1, 0.4, 7.0, 3.2, "Expansion board + TMC2209", right=["DIR", "STEP", "EN", "GND"], color="#fff8c5")
    esp = pins_box(a1, 5.9, 7.0, 3.2, "ESP32 DevKit V1 (30-pin)", left=["GPIO27", "GPIO26", "GPIO25", "GND"],
                   right=["GPIO13", "GPIO16 (RX2)", "GPIO17 (TX2)", "GPIO32", "GND ", "GPIO33"], color="#ddf4ff")
    srv = pins_box(a1, 11.4, 7.4, 3.2, "SG90 servo", left=["orange = signal"], color="#dafbe1")
    rad = pins_box(a1, 11.4, 5.85, 3.2, "LD2450 radar (primary)", left=["TX", "RX"], color="#dafbe1")
    lim = pins_box(a1, 11.4, 3.85, 3.2, "KW12-3 limit switch", left=["NO", "COM"], color="#dafbe1")
    old = pins_box(a1, 11.4, 1.85, 3.2, "LD2410C (fallback, optional)", left=["OUT"], color="#eaeef2")
    for p, q, c, l in [("STEP", "GPIO26", BLU, "step"), ("DIR", "GPIO27", BLU, "direction"), ("EN", "GPIO25", BLU, "enable"), ("GND", "GND", BLK, "ground")]:
        line(a1, drv[p], esp[q], c, l)
    line(a1, esp["GPIO13"], srv["orange = signal"], GRN, "servo signal", mid=10.2)
    line(a1, esp["GPIO16 (RX2)"], rad["TX"], PUR, "radar data", mid=10.5)
    line(a1, esp["GPIO17 (TX2)"], rad["RX"], PUR, None, mid=10.8)
    line(a1, esp["GPIO32"], lim["NO"], ORG, "home switch", mid=10.35)
    line(a1, esp["GND "], lim["COM"], BLK, None, mid=10.65)
    line(a1, esp["GPIO33"], old["OUT"], GRY, "fallback", mid=10.95)
    mot = pins_box(a1, 0.4, 2.4, 3.2, "NEMA 11 motor, 4 wires", right=["black", "green", "red", "blue"], color="#eaeef2")
    ter = pins_box(a1, 5.9, 2.4, 3.2, "Expansion board motor terminal", left=["1A", "1B", "2A", "2B"], color="#fff8c5")
    for p, q, c in [("black", "1A", BLK), ("green", "1B", GRN), ("red", "2A", RED), ("blue", "2B", BLU)]: line(a1, mot[p], ter[q], c)
    a1.text(0.4, -1.35, "Expansion board setup before anything else:\nDIP switches 1, 2, 3 all OFF (1/8 step).  TMC2209 pot to Vref 0.85 V (= 0.6 A) with the motor UNPLUGGED.\nDriver's EN pin on the expansion board's EN.  Motor buzzes but won't turn: swap black and green.  Never unplug the motor with 12 V on.",
            fontsize=10, va="bottom", bbox=dict(fc="#fff8c5", ec="0.6"))
    a1.text(7.5, 7.75, "Same GPIO numbers on the 38-pin NodeMCU-32S. BOOT button (GPIO0) = manual test drop. KW12-3 NC leg unused.", fontsize=9.5, ha="center")

    a2.set_title("2. POWER WIRING (thicker wire for the 12 V run, 22 AWG is fine)", fontsize=14, weight="bold", loc="left")
    psu = pins_box(a2, 0.4, 6.3, 3.2, "12 V 2 A adapter + jack", right=["+12 V", "GND"], color="#ffebe9")
    drvp = pins_box(a2, 5.9, 6.3, 3.2, "Expansion board power", left=["VMOT (+12 V)", "GND"], color="#fff8c5")
    buck = pins_box(a2, 5.9, 4.3, 3.2, "MP1584EN buck, fixed 5 V (meter it first!)", left=["IN+", "IN-"], right=["OUT+", "OUT-"], color="#ffebe9")
    e5 = pins_box(a2, 11.4, 6.3, 3.2, "ESP32", left=["VIN", "GND"], color="#ddf4ff")
    s5 = pins_box(a2, 11.4, 4.6, 3.2, "SG90 servo", left=["red (5 V)", "brown (GND)"], color="#dafbe1")
    r5 = pins_box(a2, 11.4, 2.55, 3.2, "LD2450 (and LD2410C if fitted)", left=["VCC (5 V)", "GND"], color="#dafbe1")
    line(a2, psu["+12 V"], drvp["VMOT (+12 V)"], RED, "+12 V")
    line(a2, psu["GND"], drvp["GND"], BLK, "GND")
    line(a2, psu["+12 V"], buck["IN+"], RED, None, mid=4.4)
    line(a2, psu["GND"], buck["IN-"], BLK, None, mid=4.0)
    for dst, bx in [((e5["VIN"]), 10.0), ((s5["red (5 V)"]), 10.3), ((r5["VCC (5 V)"]), 10.6)]: line(a2, buck["OUT+"], dst, ORG, None, mid=bx)
    for dst, bx in [((e5["GND"]), 9.6), ((s5["brown (GND)"]), 9.8), ((r5["GND"]), 10.9)]: line(a2, buck["OUT-"], dst, BLK, None, mid=bx)
    a2.add_patch(Circle((11.0, 4.37), 0.16, fc="white", ec=ORG, lw=2, ls="--"))
    a2.text(7.3, 0.35, "Dashed circle: 470 uF capacitor at the servo, ONLY if the ESP32 restarts when the finger moves.\nAll grounds tie together: adapter, expansion board, buck, ESP32, servo, radar, switch COM.\nUSB can stay plugged in for the serial console while 12 V is on.",
            fontsize=10, ha="center", bbox=dict(fc="white", ec="0.6"))
    fig.savefig(os.path.join(IMG, "wiring.png"), dpi=100, bbox_inches="tight"); plt.close(fig)
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

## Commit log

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2026-09-24 Standard PlatformIO layout at the repo root, pinned platform, secrets kept out of git
    platformio.ini, src/ and include/ move from firmware/ to the root, with lib/ and
    test/ as PlatformIO creates them. Board is nodemcu-32s (38-pin ESP32-S NodeMCU),
    platform pinned to espressif32@6.7.0 (Arduino core 2.0.16) and both libraries
    pinned. Network and update passwords come from secrets.ini, which is ignored;
    secrets.ini.example is the template. Line endings fixed by .gitattributes.
    Python tool dependencies listed in tools/requirements.txt.
    [config.h, main.cpp]
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2026-09-25 Rev C.1 owner design and docs: M1 fix, M2, LD2450, fairlead + KW12-3, finger v2
    Committed as the mechanical owner left the working tree, STL orientations
    included (bracket.stl is the owner's print orientation, not the generator's).
    cad/generate.py was run 2026-09-25: every part watertight, every clash check
    clear, and every STL except bracket (orientation) matches its output.
    [BOM.csv, DropSpider-inline.3mf, bracket.stl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]
2026-09-25 tools/esptool_noreset.py: run esptool without holding the board in reset
    [esptool_noreset.py]
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2026-09-25 scripts/update_firmware.bat: one double-click update, WiFi or USB
    WiFi path retries up to 3 times. USB path builds, prompts for the IO0 and EN
    buttons, and writes through tools/esptool_noreset.py, because the plain pio
    USB upload holds this board in reset. Retires tools/flash_usb.bat,
    flash_ota.bat and flash.ps1, which that problem made unreliable.
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2026-09-25 Board in use is the 30-pin ESP32 DevKit V1
    Flashed and on the network. Pin map, build guide drawing, wiring guide, doc 02
    picture and doc 04 updated for its 30-pin header (pin names checked against a
    photo). USB update now tries the automatic upload first and only asks for the
    BOOT and EN buttons if that fails. Firmware and GPIO numbers unchanged.
    [config.h, diagrams.py, esptool_noreset.py]
2026-09-25 Commissioning log: the failed board was a new one, model not confirmed
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2026-09-25 Build guide: protoboard layout, rails instead of splices, KW12-3 leg order
    New section 05b draws one quarter of the snappable protoboard hole by hole:
    ESP32 on female sockets, signal male pins in the same 3-hole copper groups,
    5 V and GND on the side rails, two solder bridges. Splices are gone from the
    power tree, the connection table and the soldering steps. KW12-3 legs from the
    hinge end are COM, NO, NC as read off the owner's part.
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2026-09-25 5 V supply is a fixed-5 V MP1584EN mini buck, not the LM2596
    Parts list, doc 02, README, both guides and the wiring picture updated: meter
    the output (4.95 to 5.05 V) instead of setting a pot. Peak 5 V load about 1 A
    against about 1.5 A comfortable. LM2596 kept in the parts list as a spare.
    [BOM.csv]
2026-09-25 Doc 05 step 19: the buck is fixed 5 V, meter it rather than set it
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2026-09-26 LD2450 holder on the device, looking into the room (owner ruling)
    New part ld2450_holder.stl from cad/sensor_mount.py: glues under the bracket's
    servo end, holds the radar upright (Hi-Link figure 6) in edge grooves, tilted
    20 degrees down, with back windows for the plug. Prints on its side with no
    supports. generate.py: watertight, no clashes, 0.0 mm3 against the spool's
    2 mm swept clearance, nothing above the bracket underside. New step 7 render;
    assembly, exploded and install pictures redrawn. Docs 01, 03, 06, BOM, cad
    README and the build guide updated. The owner's bracket.stl and finger.stl
    kept as committed; bracket and printed parts unchanged.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
    [BOM.csv, ld2450_holder.stl]
2026-09-26 Install is under a porch overhang, people approach from outside
    Radar holder unchanged: its servo end points out from under the porch toward
    the approach. Wording in docs 03, 06, the holder script and the build guide
    corrected from 'room side'. Porch dimensions not yet known; install picture
    and doc 06 heights still show the doorway example.
2026-09-26 Radar mount tilts on one M3 bolt: glued fork plus pivoting cradle
    Owner ruling: pivotable on a single M3 bolt. ld2450_holder.stl replaced by
    ld2450_fork.stl (glued under the servo end, two ears) and ld2450_cradle.stl
    (knuckle between the ears, radar in edge grooves). sensor_mount.py checks every
    tilt from 0 to 50 degrees: no clash with any part, nothing above the bracket
    underside, spool 2 mm clearance kept. Tilt now set on site, start at 20 degrees.
    Parts list gains the M3 bolt and nut. Owner's bracket.stl and finger.stl kept.
    [BOM.csv, ld2450_cradle.stl, ld2450_fork.stl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]
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2026-09-26 Radar fork lightened: 2 mm plate and ears, smaller ears
    Same design, owner's request: plate 3 to 2 mm and shortened, ears 3 to 2 mm
    thick and 6 to 4.5 mm radius, inner faces unchanged so the cradle is untouched.
    Fork 1.7 to 0.8 cm3. Rechecked clear of every part at every tilt 0 to 60 deg.
    [ld2450_fork.stl]
2026-09-26 Fork back as it was; radar cradle lightened for a fast print
    Owner correction: the fork was fine, the cradle is what gets lighter. Fork
    restored to 1.7 cm3. Cradle 5.7 to 3.0 cm3: rails 2.5 mm wide, back 1.2 mm with
    a third window (a ladder), 4 mm behind the board instead of 6, knuckle radius
    5 to 4 and a narrower neck, knuckle width unchanged so it still fits the fork.
    Clear of every part at every tilt 0 to 60 deg; board still gripped.
    [ld2450_cradle.stl, ld2450_fork.stl]
2026-09-26 Radar flipped in the cradle: antenna side to the face plate, headers open
    Owner: the LD2450's circuit side carries pin headers, so the antenna side lies
    against the cradle's face plate (two big windows, 1.2 mm ribs) and the header
    side faces back, open. Header end goes in last (bottom): headers plus dupont
    plugs, 24 mm deep, clear everything at 30 to 60 deg; at the top end they would
    hit the bracket above 40 deg. Cradle 2.3 cm3. Still clear at every tilt 0 to 60.
    [ld2450_cradle.stl]
2026-09-26 Lightweight fork with the flipped cradle (owner's pick)
    Fork 0.8 cm3: 2 mm glue plate, 2 mm ears of 4.5 mm radius, ear inner faces
    unchanged so the cradle's knuckle fits as before. Checked clear at every tilt 0
    to 60 deg with the current cradle. Bolt: M3 x 20 and a nut.
    [ld2450_fork.stl]
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2026-09-26 Spacers and shims 9.6 mm OD: slide into the ratchet disk's 10.2 mm hole
    10.0 mm printed too tight (owner's test fit). Clash and clearance checks pass.
    [shim_1mm.stl, shim_2mm.stl, spacer_A_6mm.stl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]
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2026-09-26 Line: 6 lb nylon monofilament, no elastic, no braid (owner)
    The mono's stretch is the shock absorber (estimate 12 N peak if the motor
    loses grip, snaps at about 27 N). Elastic snubber only if braid or
    fluorocarbon is ever used. CLAUDE.md hard constraint reworded to match.
    [BOM.csv]
2026-09-26 Fit check fixes, finger hub onto the spline, all parts regenerated
    Finger: 7 mm plate level with the ledge (z 35..42), hub down to the SG90
    spline (owner: spline 3.4 mm, tip about 2 mm short of the ledge), 1.5 mm
    floor, screw from the top. Fits from the Fable fit check, each verified in
    code: HF0612 bore 10.0; ratchet hole 10.6 and recess 30.5; body screw pilots
    to z 12.4; flap pin hole 2.5; cradle groove 2.2; finger screw hole 2.5;
    spacer A 12 OD stops on the disk face (was falling 2 mm into the hole);
    spacer B 8 mm nose on the 606ZZ inner ring. Bracket exported base down,
    same shape as the owner's copy. All checks pass.
    [bracket.stl, fairlead_flap.stl, finger.stl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]
2026-09-26 Flap hinge pin: M2 bolt, free in the flap, threaded into the body (owner)
    Filament pin was too tight. Docs, BOM and build guide updated; no STL change.
    [BOM.csv]
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2026-09-26 Fix: fairlead bore was never cut (printed solid)
    The bore void had an extra y flip that put it at y -78, missing the block.
    Guard added in trumpet() and a line-path check in the fairlead report.
    Found by the owner.
    [fairlead_body.stl]
2026-09-26 Fairlead body reinforced from the rail down (owner's ask, designed by Fable)
    Rail 6 mm thick and wider; thin spine replaced by a 4 mm back plate with two
    ribs (C channel); plate carried under the block with a gusset; hinge boss
    runs into the switch plate (old 6 x 6 mm joint gone); rest stop thickened.
    19.2 to 32.8 cm3. All checks pass: line path clear, hard stop 14.75 deg,
    roller push 4.33 mm, spool clearance 0.0, no clashes. 5 mm brim.
    [fairlead_body.stl]
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2026-09-27 Fairlead: no glue. Ribs flush to the bracket; 2x M3 countersunk screws
    Ribs and back plate now run up to the bracket underside (y 3 under the pad,
    y 4 under the base); they stopped 5 mm short. Fairlead screws on with 2x M3
    flat-head screws from the ceiling side through the x = -32 pad holes into
    2.5 mm rail pilots; bracket code countersinks those holes (printed bracket:
    by hand, 8 mm bit). All checks pass.
    [BOM.csv, bracket.stl, fairlead_body.stl]
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2026-09-27 Handoffs: task 1 firmware and vertical-face mount strategy; docs sweep
    CAD README lessons from this session's fixes; open items V16 to V19 (fits,
    servo type, finger height, fairlead print); CLAUDE.md task list points at
    the new handoffs and drops the stale missing-pictures note.
2026-09-27 Firmware Rev C.1: motor-led drop, unload on release, seat move on lock
    - Release: driver on, finger out while the spool winds up 1/12 turn (M2),
    then a powered drop to dropmm at droprpm. FastAccelStepper 0.33.14 has one
    acceleration per move, so the machine task switches from dropacc to dropdec
    just before the stop must begin, with a margin against overshoot.
    - Lock: finger in, seat move 1.2/12 turn at 30 rpm, driver off, servo off.
    - rel now unloads and releases with the motor on, and holds the spider.
    - V14: home remembered in flash after a switch-stopped rewind and lock;
    boot accepts an open switch when it says home. Boot never rewinds.
    - New settings dropmm, droprpm, dropacc, dro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
    [config.h, console.cpp, machine.cpp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]
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2026-09-27 Wall install: the owner's hinge-and-cord draft replaces the braced shelf (hinge_plate, 2x hinge_clip, cords)
    Three small flat prints and two M3 pins: a plate screwed to the beam with forks at the bottom and eyes at the top, two clips bolted on the pad carrying the knuckles, cords from the far end up to the eyes. The device hangs 45 mm below the ceiling because a cord only pulls and its anchor must sit above the hinge. CAD-checked: watertight, clears every part, pins line up, swings clear, 63 N cord pull on a line snap. Not printed. The braced wall_mount stays in cad/wall_mount.py as the fallback, out of the print list.
    [BOM.csv, hinge_clip.stl, hinge_plate.stl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]
2026-09-27 Wall install draft to the owner's picture: tall hinge plate, hinge at the top, a pushed 40 degree strut at each end, tie bar across the far edge
    The plate is a frame down the beam with the hinge forks on its top rail and a fork at the bottom of each leg. A strip on the device's far edge carries a lug at each end; a printed bar with an eye at each end joins lug to leg. The bar is pushed by the device's weight, so it is a bar and not chain. Five flat prints, 69 cm3. CAD-checked: watertight, clears every part, six pins line up, screwdriver paths clear, swings clear to 65 degrees, 20 N push on a line snap against 160 N buckling. Not printed.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
    [BOM.csv, hinge_plate.stl, strut.stl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]
2026-09-27 Handoff: inverted device on metal corner braces (owner's redesign), model probe and doorway-dropper prior art
2026-09-27 Handoff: inverted device, cad/inverted.py written and unrun; mockup is the next session's first job; brace length note
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2026-09-27 Inverted mockup: inverted.py runs clean with 6 in braces at the base's ends (block trimmed to z 24 to 93), inverted_install.png rendered and put atop the handoff
    [render.py]
2026-09-27 Inverted mockup, owner's corrections: radar on the device under the servo end, braces stand up the beam (base 160 below the ceiling), electronics room checked on the pad, labels point at their parts
    [render.py]
2026-09-27 Inverted install into the docs: doc 06 section, doc 09 fairlead_base, doc 01 line exit, doc 05 steps, doc 08 V10 and V18, BOM, drilling drawing, fairlead_base.stl
    [BOM.csv, fairlead_base.stl]
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2026-09-28 Inverted install, Fable check fixes: brace bolt zones, lead routing, boss under the short block screw, 7 mm line hole, radar fork bolted not glued, load line corrected, stale handoff numbers flagged
    [BOM.csv, fairlead_base.stl]
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2026-09-28 Flap: the slot's outer prong widened from 1.2 to 3.8 mm (owner: too thin); both installs' checks pass, stops unchanged
    [fairlead_flap.stl]
2026-09-28 Radar and aluminum siding (blocks 24 GHz completely) in doc 06 and the build guide; build guide gets the inverted install, 17.0 bearing seat and wider flap prong; rebuilt
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2026-09-28 No glue on the radar: glued ld2450_fork retired, ld2450_fork_screw bolted with 2x M3 is the radar fork in both installs; hot-glue dab on the board replaced by a zip tie
    [BOM.csv, ld2450_fork.stl]
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2026-09-28 Build guide: step-by-step inverted fairlead install with a close-up picture; separate power board removed (expansion board and buck hot-glued beside the main board, 12 V straight from the jack); stal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
    [render.py]
2026-09-28 Build guide: turned over to the inverted install (ceiling steps, ceiling placement and ceiling line formula removed; doc 06 keeps the ceiling install); web page picture matched to src/web.cpp; radar 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
2026-09-28 Docs: one job per file (owner's repo-docs standard). ROADMAP.md and CHANGELOG.md added; README doc map marks each file's role; handoffs cut to future work only (task 1 now the spool-to-flap fix and T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
2026-09-28 Inverted drilling template: drawn as seen from outside the base face (it was mirrored: the view from inside), each hole labelled (line, fairlead block, radar fork) with a centre cross, the block's an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
2026-09-28 Bracket: line pass-through (7 mm at x 25, z 45) and the four inverted-install screw holes (fairlead block, radar fork) printed in instead of drilled; only bracket.stl exported; inverted checks pass
    [bracket.stl]
2026-09-28 Fairlead v2 for the inverted install (owner): switch on the outer face above the flap, legs up toward the base, flap the lowest point; new fairlead_flap_inv (tab under the roller); block prints mount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
    [fairlead_base.stl, fairlead_flap_inv.stl]
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2026-09-28 Fairlead v2 edits (owner): line bore 4.0 mm with 7 and 9 mm mouths; switch plate solid, 2x M2 x 12 self-tapping 6.5 deep, no slots or nuts; rest pad shortened 1.25 mm (flap rests at 9.5 deg); only fa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
    [fairlead_base.stl]
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2026-09-28 HF0612 one-way bearing: spool_body hole 10.7 (tight press) and disk center hole 11.0 (slip), owner fit report; only those two STLs exported, holes measured 10.70 and 11.00. Bearing drawn as its own p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
    [spool_body.stl, spool_ratchet.stl]
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2026-09-28 Fairlead block rounded (column edges r 1.5) with 3 through-windows, 15.7 to 12.8 cm3, inverted checks unchanged, only fairlead_base.stl exported; build guide pictures redrawn with the spoked spool an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
    [fairlead_base.stl]
2026-09-28 HF0612 hole in spool_body 10.2 (owner: 10.7 printed 10.7, loose); only spool_body.stl exported, hole measured 10.20
    [spool_body.stl]
2026-09-28 HF0612 hole in spool_body 10.3 (owner: 10.2 tight); only spool_body.stl exported, hole measured 10.30
    [spool_body.stl]
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2026-09-29 Spool stack: new spool_shield (flat 1.5 disc, 64 across) between ratchet and spool body; boss and recess removed, all flat-face sandwich centred by the HF0612 through three 10.3 holes and the 3 screw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
    [spool_body.stl, spool_ratchet.stl, spool_shield.stl]
2026-09-29 Ratchet disk a plain 7 mm plate (no lip), flat both faces, printed shield face down; 0.4 edge breaks on bed-side bearing holes; assembly: screw the stack first, then press the HF0612 through; finger 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
    [spool_body.stl, spool_ratchet.stl, spool_shield.stl]
2026-09-29 bearing_retainer: 2 mm plate on the end plate's outside face holds a loose 606ZZ in, 12 mm rod hole, 2x M3 into pilots drilled through the end plate; no clashes in either install; build note: owner's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
    [bearing_retainer.stl]
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2026-10-01 fairlead_flap_inv: owner's redesign (tab to z 51.67, web fills the notch by the prong, slot 1.43 deeper) kept as the print STL; inverted.py builds it to within 3.5 mm3; inverted checks unchanged
    [fairlead_flap_inv.stl]
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2026-10-01 Inverted install turned end for end to the owner's build: servo end at the beam; radar fork to the pad end (x -80, z 38.5 and 72.5), view unblocked, passes under the beam, cradle clear 20 to 90 deg; 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
    [render.py]
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2026-10-01 Build guide: gold antenna pads behind the cradle's windows, face plate toward the beam (was wrongly 'open side faces the beam')
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2026-10-02 Commissioning: jog + turns the rod clockwise from behind the motor, dir 1 correct
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2026-10-02 Spool redesign handoff: line anchor spec (where the hole goes, how the line ties to a filament stub in a window, teardrop hole angled with the winding, set screw ruled out)
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2026-10-02 One-piece spool (Rev C.3) and finger hub 2.5 mm shorter
    spool_onepiece: ratchet, separator, barrel and flange in one part, no screws, 14.5 long (owner's stack measured 14.6), prints ratchet face down with no supports. HF0612 (owner measured 9.99 x 11.89) in a 10.2 hole between a printed shoulder and a 9.9 snap lip. Line hole printed in. spool_onepiece_ribs: crush-rib hole instead. Not yet printed or fitted.
    finger: hub onto the spline 2.5 shorter, plate still 7, same spline grip; finger sits 2.5 nearer the servo.
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2026-10-02 Finger: screw floor 3.5 mm (was 1.5, too thin for the horn screw)
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2026-10-05 Save work before restart: owner's slicer projects (v2, v3 invert), build123d fairlead trial STLs, fairlead_flap_inv.stl re-exported by generate.py
    No design change. Spool Rev C.4 not started; baseline checks all pass (python generate.py, 2026-10-04).
2026-10-05 Spool Rev C.4: barrel centred on the line (separator 3.75), body ends flat at 14.25, spool_cap (r 32 disc, 3 lugs in the spoke windows, spacer B clamps it); fairlead_base_ptfe (straight 4.3 bore) and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
    generate.py: OP_SEP_T 1.5 to 3.75, flange cone and rim removed, CAP_* constants, cap_lug_polys, spool_cap, spool_cap_print; onepiece_checks now covers the cap (lugs drop in, locked at 1.5 deg of play, face contact 634 mm2, spacer B on the cap 25 mm2, print orientation, feed point z 45 centred with 1.75 each side), stack 16.25 long, spacer B 51.25 (1.75 less shim than C.3). Stub check limited to the tilt the cap allows (9 deg).
    inverted.py: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
2026-10-05 Docs for spool Rev C.4, the thread and the PTFE tube: line to bonded nylon size 69, spider to 30 g, cap and stack in doc 01 and doc 05, PTFE trial in doc 09 and steps 24a and 24b, handoff trimmed to 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
    Owner rulings 2026-10-04: bonded nylon upholstery thread size 69 (Tex 70) black replaces 3 lb mono (coil memory sprang loose wraps); spider brought to about 30 g; print body and cap and bench ten drops; PTFE tube trial by wedging in the plain block's mouth, the ptfe block only if it walks; deep-groove spool and slack take-up arm held. Handoff now says loops on the spool mean slack reached it (spider stopped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
2026-10-05 PTFE block without lightening windows (owner 2026-10-05: print time beats material); rule in CLAUDE.md; tube path picture in doc 09
    fairlead_base(ptfe, windows) and fairlead_base_print(ptfe, windows); PARTS fairlead_base_ptfe exports windows=False (15.7 cm3); inverted.py checks run on the same variant and pass (tube clear of spool and cap, fits the bore, line path clear). Only fairlead_base_ptfe.stl exported. Bambu Studio's command line could not slice the two variants for a time comparison while its window was open.
2026-10-05 Spool cap screwed to the body: 3x M3x8 into pilots in the spokes (boss r 3.5, 2.25 wall), cap a plain 2 mm disc with 3.4 holes, lugs dropped; prints line-side face down
    Owner 2026-10-05: a cap held only by the snug rod stack can lift up to the stack's end play, and a 0.29 mm thread walks into that crack at the barrel's corner; the stack cannot be tightened to close it because the spool must spin free when the clutch is unlocked. Checks: cap flat on the body (0.00 overlap), screws pass the holes, body 100% full within 2 mm of each pilot, heads clear of everything, every other check unchanged. Exported only spool_onepiece, spool_onepiece_ribs, spool_cap. Docs 01, 05, handoff, build guide, chan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
2026-10-05 Spool bearing hole: one plain 10.2 through the far face, no snap lip (owner carved the C.3 lip out); ribs variant dropped, one spool STL; cap keeps three 1.5 mm lugs (alignment, hold the anchored thr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
    Owner 2026-10-05: "the entire bushing should just be the narrower smaller diameter"; "keep the rib insert disc - it helps with alignment and securing the string"; "the lugs dont need to be so high". Checks pass: lugs drop in, cap flat (0.00 overlap), lugs meet the spokes at 1.5 deg, screws pass, pilots walled, hole plain with the bearing 0.11 under the cap, prints with no overhang. Exported spool_onepiece and spool_cap only; spool_onepiece_ribs.s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
2026-10-05 Spool cap centre hole 11.0 (was 7.0): spacer B passes through and bears on the one-way bearing, never the cap (owner opened his printed cap to 10 mm); 606ZZ stack keeps the C.3 shims (53.36, 0.36 pla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
2026-10-06 Spool C.4 handoff: no rewind until the limit switch is proven by hand (two rewinds stalled on 2026-10-06)
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2026-10-07 Refuse a second wind from the top (bead passes the flap, switch only blips); full-count rewind ends motor off, finger out (no lock into a slipping or reversed one-way bearing); radar finds its own wi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
2026-10-07 Switch stop and stall both back off 1/8 turn and hold with the motor on; a stall waits on the fault for lock (owner: the motor never loses power before the finger holds); setrel 30 saved on the board
2026-10-07 Rewind locks by itself after the switch (or a stall) instead of hanging the spider on the motor: on 2026-10-06 it slid about 0.6 m with the driver on and no command
2026-10-07 Driver held still 200 ms after switch-on before the first step (stealthChop tuning; chirp on release), built, not yet flashed; log: one-way bearing slips at the switch stop, rewind rpm 80
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2026-10-07 Handoff: the spider runs away on any downward move (motor skip, coupler or one-way bearing; slow-motion marker test first); roadmap line 2b
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2026-10-07 Coupler set screws found loose and tightened (owner); logged, handoff keeps coupler slip as a live cause
2026-10-07 Runaway persists with the coupler tightened (jog -200, whole line); logged, handoff updated
2026-10-07 Runaway audit (step 1 and 2): the motor lets go, not the coupler, bearing or finger; dead stop at the switch in stealthChop with no driver reset; Codex findings verified and folded in
2026-10-07 Runaway fix: every move ends in a lock, driver reset with the finger in after a dead stop, nudge before the settle; owner's hand test (motor nearly free, driver reported on) logged; dropacc 80000 sav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
2026-10-07 DIP switch mapping from the owner's photo: switch 1 is the module's RX pin (standstill current), switch 3 is MS1 and stays OFF; audit, handoff, doc 02 and log corrected
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2026-10-07 Log: owner's correction, the motor stayed plugged in for every test; hot-unplug row withdrawn
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2026-10-07 Driver logic rail never connected: V row 2.7 V by leakage, 1.8 mV with the signal wires off (owner's meter); audit, doc 02, handoff, changelog and log updated; 3V3 jumper owed
2026-10-07 Log: 3V3 jumper fitted (V and RX 3.3 V), line 1333 saved, first rewind under the new wiring reached the switch, reset and locked
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2026-10-07 Log: second rewind 152 mm to the switch, reset and locked, home
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2026-10-07 LD2450: radar wake and radar reset console commands; module answers every command, sends no target frames
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

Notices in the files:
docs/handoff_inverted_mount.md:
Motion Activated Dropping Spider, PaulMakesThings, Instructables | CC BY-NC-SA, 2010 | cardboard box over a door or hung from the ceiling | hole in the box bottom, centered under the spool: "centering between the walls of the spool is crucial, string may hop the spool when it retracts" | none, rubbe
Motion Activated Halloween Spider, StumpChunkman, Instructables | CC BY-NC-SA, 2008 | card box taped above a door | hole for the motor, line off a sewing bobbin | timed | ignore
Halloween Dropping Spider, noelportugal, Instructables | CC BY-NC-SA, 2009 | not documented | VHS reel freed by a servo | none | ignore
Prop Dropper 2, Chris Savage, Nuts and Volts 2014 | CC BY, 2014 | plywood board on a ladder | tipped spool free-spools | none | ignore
